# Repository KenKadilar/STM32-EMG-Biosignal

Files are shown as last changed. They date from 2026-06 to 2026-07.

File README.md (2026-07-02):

# CAN-Networked Real-Time Myoelectric Gripper Firmware

A self-contained myoelectric gripper on STM32 firmware: it reads a forearm muscle, classifies the gesture on-chip in real time, drives a gripper, reports its state over a CAN bus, and fails safe. It rebuilds the embedded layer of my M.Sc. prosthetic-hand thesis on industrial-grade firmware (STM32, FreeRTOS, CAN).

https://github.com/user-attachments/assets/c445c9bf-50ab-4b18-980c-f69603f6f55b

**~30s demo:** flex, the gripper actuates, the state broadcasts over CAN, then the failsafe (pull an electrode, the gripper holds).

**Tech stack:** STM32F446 (Cortex-M4F), FreeRTOS, CAN (MCP2515, hand-written register-level driver), on-chip DSP and classification, timer and DMA sensing, IWDG watchdog, PlatformIO, GitHub Actions CI

## What this is

The board is autonomous: the muscle drives everything, and the laptop is only a viewer. TIM2 triggers the ADC on the EMG pin at 1 kHz, DMA parks each sample in RAM, and a lightweight detector runs per sample inside the DMA-complete interrupt, so a flex is caught the instant it happens and handed to the FreeRTOS tasks through queues. The tasks drive the gripper, stream telemetry, broadcast state on the CAN bus, and pet the watchdog.

The hard biosignal part (single-channel sEMG gesture detection on a microcontroller) comes from my published thesis. The work here is the industrial-firmware layer around it: a real-time OS, a CAN stack written from the datasheet, on-chip DSP, and a safety layer.

## Highlights

- **One muscle, decided on-chip.** TIM2 to ADC to DMA at 1 kHz with zero CPU per sample; the baseline-tracking dip detector runs in the DMA ISR, so a flex is caught immediately.
- **FreeRTOS with a safety-by-priority design.** Four tasks (servo, comms, CAN, watchdog) with priorities and queue mailboxes. The watchdog task is the lowest priority on purpose: if any higher task hangs, it never runs, never pets the IWDG, and the chip reboots itself.
- **A CAN stack written from the datasheet.** There is no mature MCP2515 driver for STM32 and stm32cube, so the SPI instruction set, register map, and logic are hand-written, brought up in four verified steps, and checked end to end by a second CAN node.
- **On-chip DSP.** A 50 Hz biquad notch rejects mains hum before detection.
- **Fails safe.** A signal-loss hold keeps the current grip if an electrode drops, backed by a hardware IWDG watchdog.
- **A full-stack build.** The gripper is a 3D-printed involute-gear pincer I designed in SolidWorks and drove from a single SG90.

## Architecture

The board is autonomous; the laptop only flashes it and views the trace.

```mermaid
flowchart TD
    EMG[EMG sensor] --> ADC[ADC + DMA<br/>1 kHz]
    ADC --> BRAIN[Brain<br/>DMA ISR]
    BRAIN -->|flex| MB([mailBox])
    BRAIN -->|flex| CM([canMailBox])
    MB --> SV[servoTask] --> GR[Gripper]
    CM --> CT[canTask] --> BUS[CAN bus]
    ADC --> CO[commsTask] --> LAP[Laptop]
    WD[watchdogTask] --> IWDG[IWDG reboot]
```

The decision lives in the **interrupt**: `HAL_ADC_ConvCpltCallback` fires at 1 kHz on every DMA sample and runs the detector (baseline, notch, dip), then `xQueueSendFromISR`s a token into both `mailBox` (to servoTask) and `canMailBox` (to canTask). The token's existence is the signal that a flex happened; its value is unused, and the queues do their own locking, so there is no manual volatile or atomic reasoning.

Four tasks run under the scheduler (higher number is more urgent):

1. **servoTask (priority 3):** a token toggles the grip; `servo.ease()` glides toward the target each cycle (slew-limited). The 5 ms receive-timeout also paces it at about 200 Hz.
2. **commsTask (priority 2):** every 20 ms, streams the `raw, centered, valid` trace to the laptop viewer over USART2.
3. **canTask (priority 2):** a token sends an immediate gesture frame (0x100); a 200 ms timeout sends a status heartbeat (0x101). Both carry `[gripper closed?, electrode attached?]`.
4. **watchdogTask (priority 1, lowest):** every 500 ms, pets the IWDG. The low priority is the safety: a hung higher task starves it and the chip reboots.

## The CAN work

There is no mature MCP2515 driver for STM32 and stm32cube, so the driver is written from the datasheet by hand: the SPI instruction set and register map live in [`src/Mcp2515Registers.h`](src/Mcp2515Registers.h) (each constant carries its datasheet name) and the logic in [`src/Mcp2515CanBus.h`](src/Mcp2515CanBus.h). It was brought up in four verified steps:

1. **Reach the chip over SPI**, reset it, and read `CANSTAT` back (`0x80` = Configuration mode).
2. **Configure and go live**: set the bit timing (8 MHz crystal at 500 kbps) and switch to Normal mode.
3. **Loopback frame**: build a frame, transmit it internally, and read it back (no bus needed).
4. **Two-node transmit**: send real frames over `CANH/CANL` to a separate node.

In the running firmware the gripper broadcasts a 2-byte payload `[gripper closed?, electrode attached?]` as an immediate gesture frame (`0x100`) on each flex and a status heartbeat (`0x101`) otherwise. It is verified end to end by an independent second node, an Arduino plus MCP2515 that receives and prints the frames ([`bench/arduino_can_node/`](bench/arduino_can_node/)). That node uses an off-the-shelf library, so the two sides are a deliberate contrast: hand-written driver against a stock one.

| Logic-analyzer capture | |
|---|---|
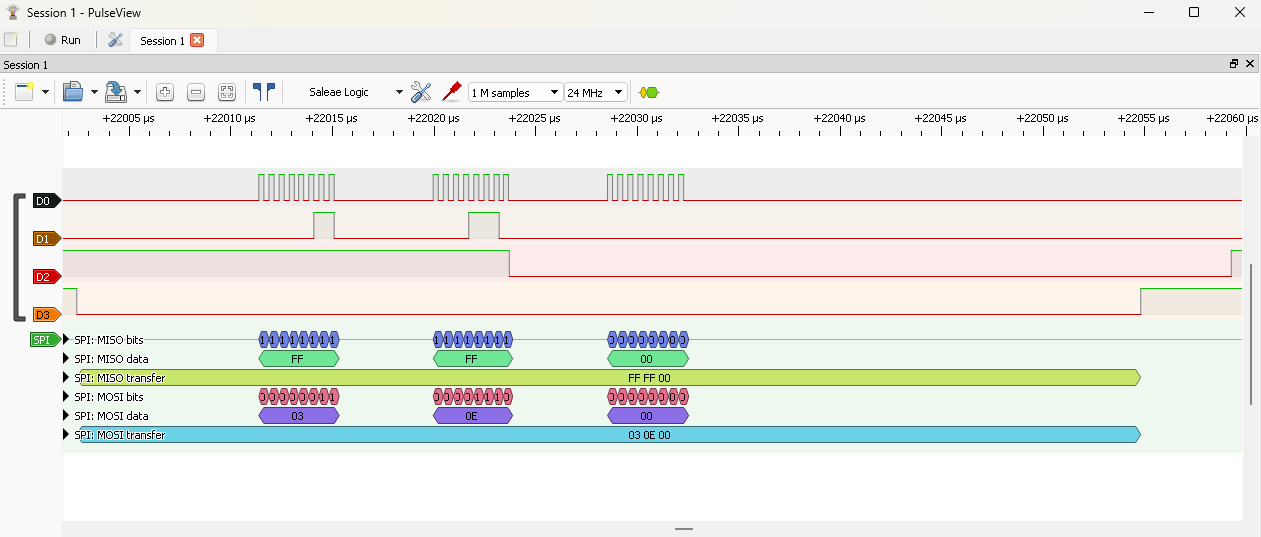
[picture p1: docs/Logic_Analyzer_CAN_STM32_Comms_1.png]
SPI decode
|  | The STM32 driving the MCP2515 over SPI, decoded live in PulseView. |

**Bus note:** the bench CAN bus is short and was initially unterminated (measured ~25 kΩ across CANH/CANL, transceiver impedance only), which produced occasional auto-retransmissions (CAN's reliability doing its job). Adding termination cleaned it up. A production harness uses 120 Ω at each end (60 Ω total).

## Mechanical

The gripper is a 3D-printed involute-gear pincer I designed in SolidWorks, so this is a full-stack mechatronics build: mechanism, electronics, and firmware.

<p>
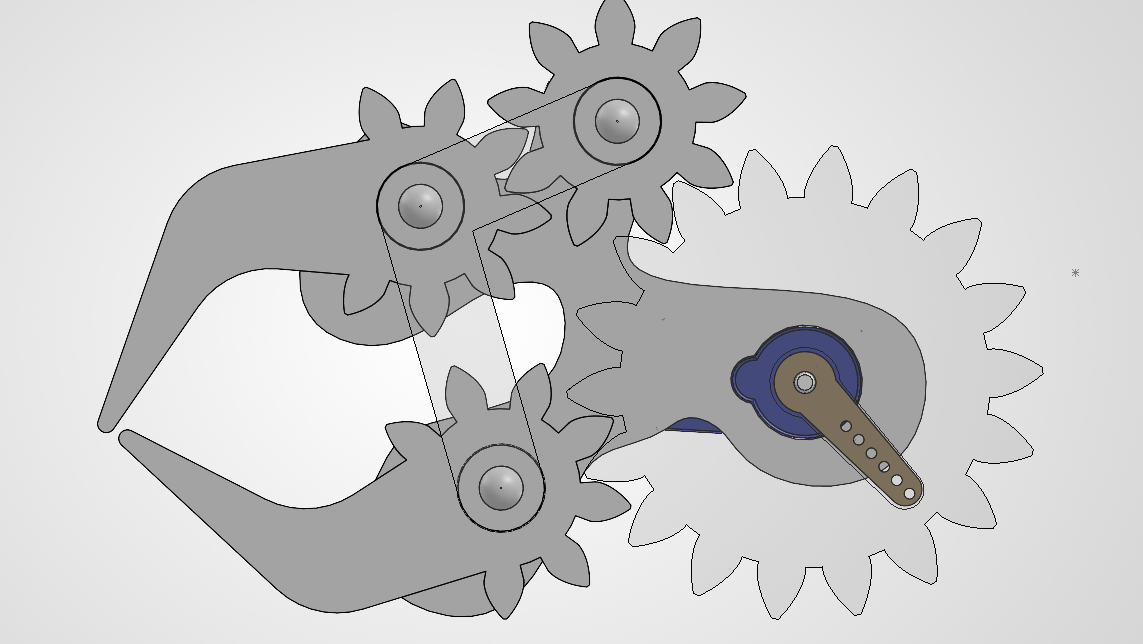
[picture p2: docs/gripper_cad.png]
Gripper CAD, top view
  
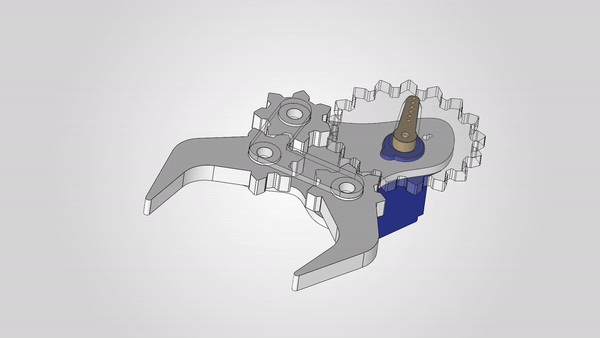
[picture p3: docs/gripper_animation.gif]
Gripper mechanism, open/close animation
  
</p>

A single SG90 drives a 28.5° pressure-angle involute spur train (z18 to z9 to z9), a 2:1 step-up to two counter-rotating fingers, giving about 108° of finger sweep in under 0.1 s and about 0.09 N·m per finger (the firmware slew-limits it so it does not slam). The gears were drawn with the in-repo `tools/gear_designer` (DXF export, undercut and bore checks).

### [Rotate the assembled gripper in 3D](cad/gripper_assembly.stl)

GitHub opens `.stl` files in an interactive 3D viewer; click the heading to spin the model. Printable parts are in [`cad/print_parts/`](cad/print_parts/).

## Specs

| Category | Value |
|---|---|
| MCU / board | STM32F446RE (Cortex-M4F, FPU + DSP), ST Nucleo-F446RE |
| RTOS | FreeRTOS, ARM_CM4F port, 4 tasks + 2 queue mailboxes |
| Sensing | TIM2-triggered ADC + DMA at 1 kHz on PA0 |
| On-chip DSP | 50 Hz biquad notch |
| Detection | baseline-tracking dip detector in the DMA ISR |
| CAN | MCP2515 over SPI2, hand-written driver, 8 MHz xtal at 500 kbps |
| Frames | gesture 0x100 + heartbeat 0x101, payload [closed?, electrode?] |
| Actuation | SG90 servo, slew-limited, on TIM4_CH1 (PB6) |
| Gear train | involute z18 to z9 to z9, 2:1 step-up, ~108° finger sweep |
| Safety | signal-loss hold + IWDG hardware watchdog (~2 s) |
| Tooling | PlatformIO (stm32cube, hard-float), GitHub Actions CI |

## Hardware and wiring

| Part | Pin | Notes |
|---|---|---|
| Grove EMG detector | PA0 (A0) | ADC1 analog envelope in |
| SG90 servo | PB6 (D10) | TIM4 channel 1, 50 Hz PWM |
| Serial TX | PA2 | USART2 over the ST-LINK virtual COM port (telemetry is one-way) |
| MCP2515 | SPI2: PB13 SCK, PB14 MISO, PB15 MOSI, PB12 CS, PA9 INT | 8 MHz xtal at 500 kbps |

SPI2 is chosen over SPI1 because SPI1's SCK is PA5, the onboard LED, which would flicker on every SPI clock. The servo runs on a separate 6 V (4xAAA) supply, not the Nucleo 5 V pin (its current spikes brown out the board); tie the servo supply ground to Nucleo GND so the PWM has a common reference. Board pinout: [`docs/STM32_NUCLEO_F446RE_Pinout.png`](docs/STM32_NUCLEO_F446RE_Pinout.png).

## Build, flash, run

PlatformIO (`framework = stm32cube`), flashed over the onboard ST-LINK.

```bash
pio run                 # build the firmware
pio run -t upload       # flash over ST-LINK (Mini-USB)

# watch the on-chip telemetry live (Python 3.12: numpy, pyserial, PyQt6, pyqtgraph)
python tools/emg_studio/chip_monitor.py --port COM6
```

The FreeRTOS ARM_CM4F port needs the FPU, so the whole image is hard-float. That takes two cooperating pieces, the `build_flags` in [`platformio.ini`](platformio.ini) and [`fpu_link.py`](fpu_link.py) (a post-script that forces the link hard-float). Both are required; removing either breaks the link. CI builds the firmware on every push.

## Bill of materials

Parts, sources, and prices (two CAN nodes, so it includes a second MCP2515 and an Arduino): [`BOM.md`](BOM.md).

## Repo structure

```
src/                 firmware: one main.cpp + a header-only class per part
  main.cpp           tasks, queues, scheduler, interrupt handlers, the 1 kHz brain callback
  Emg.h              TIM2 -> ADC -> DMA acquisition at 1 kHz
  MuscleTrigger.h    the on-chip brain (baseline, notch, dip detect, failsafe)
  Notch.h            50 Hz biquad notch
  Servo.h            slew-limited gripper PWM
  Comms.h            USB serial telemetry (TX)
  Watchdog.h         IWDG
  Mcp2515CanBus.h    hand-written MCP2515 CAN driver (logic)
  Mcp2515Registers.h the MCP2515 datasheet as code (commands, registers, values)
lib/FreeRTOS/        the kernel (ARM_CM4F port + heap_4), vendored, unedited
include/             FreeRTOSConfig.h
bench/arduino_can_node/  the second CAN node used to verify the link
tools/emg_studio/    laptop viewer/logger (chip_monitor.py)
tools/gear_designer/ the gear-profile tool used to draw the pincer
cad/                 the gripper assembly STL + printable parts
docs/                captures, CAD renders, board pinout
```

## Known limitations

- **One gesture** (a single muscle dip toggles open/close) by design; the multi-grip DTW classifier lives in the thesis, and this project's focus is the embedded system around it.
- **The CAN bus is a short bench setup** (two nodes, improvised termination), not a production 120 Ω-terminated harness.
- **The on-chip DSP is a hand-coded biquad notch**; for heavier filtering or FFT work, ARM's CMSIS-DSP (which the M4's DSP and FPU are built for) is the next step.
- **CAN is transmit-only** here (a sensor-actuator node reporting its state). Receive plus hardware ID filtering would be configured at the controller for a multi-node bus.

## Background and contact

This rebuilds the embedded layer of my M.Sc. thesis on single-channel sEMG gesture classification on a microcontroller:

- Journal article (IJANSER, 2024): https://as-proceeding.com/index.php/ijanser/article/view/1728
- Extended arXiv preprint: https://arxiv.org/abs/2504.15256

**Ken KADILAR** - embedded / firmware engineer  
Portfolio: [canarchive.com](https://canarchive.com)  
LinkedIn: [ken-kadilar](https://www.linkedin.com/in/ken-kadilar/)  
Email: kenkadilar@gmail.com

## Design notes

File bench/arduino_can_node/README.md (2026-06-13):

# Arduino CAN bench node

The **second CAN node** used to verify the STM32's CAN link end to end: first to prove the two MCP2515
modules + bus worked at all (before any STM32 CAN code existed), then as the receiver in the live
two-node demo. An Arduino UNO + an MCP2515 module (8 MHz crystal, 500 kbps), matching the STM32 side.

Note the deliberate contrast: this side uses the off-the-shelf **coryjfowler MCP_CAN** library, while the
STM32 side runs a **hand-written, register-level MCP2515 driver** ([`src/Mcp2515CanBus.h`](../../src/Mcp2515CanBus.h)
and [`src/Mcp2515Registers.h`](../../src/Mcp2515Registers.h)). The Arduino is only a known-good test partner.

- `src/receiver.cpp` (env `receiver`): prints every received frame; decodes the gripper's status (`0x101`)
  and gesture (`0x100`) frames into plain text (`servo=OPEN/CLOSED  electrode=ATTACHED/DETACHED`).
- `src/sender.cpp` (env `sender`): transmits test frames, used to validate the modules on the bench.

Build/flash one role per UNO (PlatformIO):

```
pio run -e receiver -t upload
pio run -e sender   -t upload
pio device monitor -e receiver
```

Wiring: MCP2515 over SPI (UNO D13 SCK / D11 SI / D12 SO / D10 CS / D2 INT, 5V + GND); CANH-CANH and
CANL-CANL to the other node, shared ground. See [`../../docs/wiring.md`](../../docs/wiring.md).

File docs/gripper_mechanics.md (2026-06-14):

# Gripper Mechanics, Gear Train Math

The drivetrain math for the 3D-printed involute-gear pincer. Gear values are Can's final printed
set (2026-06-08); SG90 specs from the datasheet.

## TWO THINGS TO CONFIRM (then the force/aperture numbers below compute)
1. **Which gear is on the servo shaft?** This doc assumes the **z18 is the input** (servo side),
   driving the two z9 fingers. If the servo actually drives a **z9** instead, the ratio inverts
   (see "If the servo is on a z9" below).
2. **Finger lever length `L`** = distance from a finger gear's centre to its contact/tip point
   (mm). Needed for pinch force and aperture. Measure it off the CAD/print.

## Gear set (printed)
| | teeth z | pitch d | tip (outer) d | root (inner) d |
|---|---|---|---|---|
| input gear | 18 | 48.60 | 54.00 | 41.85 |
| finger gear A | 9 | 24.30 | 29.70 | 17.55 |
| finger gear B | 9 | 24.30 | 29.70 | 17.55 |

Common: module **m = 2.70 mm**, pressure angle **28.5°**, bore 10.00 mm, backlash 0.10 mm.
Sanity (all consistent): pitch = m*z, tip = m(z+2), root = m(z-2.5), centre = m(z1+z2)/2.
At 28.5° the no-undercut minimum is ~9 teeth, so the z9 gears are right at the limit (the high
pressure angle is what lets them work at 9 teeth, a deliberate, correct choice).

## Train topology (assumed)
```
  SERVO --(z18)--mesh--(z9, finger A)--mesh--(z9, finger B)
```
- Centre distances: z18 to z9 = **36.45 mm**, z9 to z9 = **24.30 mm** (match the printed frame).
- Fingers A and B **counter-rotate** (z9 to z9, 1:1), a symmetric pincer. Good.

## Gear ratio (servo to finger)
Servo drives z18; fingers are z9. Driven/driver teeth = 18/9, so:
- **Fingers rotate 2× the servo angle** (a 2:1 *step-up*).
- **Finger torque = servo torque ÷ 2.**
- This trades torque for travel: the SG90's limited usable sweep becomes 2× as much finger
  rotation, sensible for a gripper that needs range and has torque to spare.

*If the servo is on a z9 instead:* it becomes a 2:1 *step-down*, fingers move 1/2 the servo angle,
finger torque = servo torque × 2 (more grip force, less range). Flip the numbers below accordingly.

## Servo sweep to finger sweep
- Pulse band (measured): open **1300 µs**, close **1600 µs**, giving **300 µs** of travel.
- SG90 ≈ 0.18°/µs (≈180° over 1000 µs; **calibrate yours**, SG90s vary): 300 µs ≈ **54° servo**.
- Finger sweep = 54° × 2 = **~108° per finger.**

## Speed
- SG90: 0.10 s / 60° = **600°/s** (no load). Finger = ×2 = **1200°/s**.
- 108° finger sweep ≈ **0.09 s** open to close at full speed. (The firmware slew-limits this on
  purpose, the mechanism is faster than you'd want it to slam.)

## Torque & pinch force
- SG90 stall ≈ **1.8 kgf·cm = 0.176 N·m** at 4.8 V (higher at 6 V, measure if it matters).
- Finger gear torque (÷2) = **0.088 N·m**.
- Fingertip pinch force: `F_tip = 0.088 N·m / (L/1000)` = **88 / L_mm  newtons**.
  - e.g. L = 30 mm gives ~2.9 N. L = 40 mm gives ~2.2 N. L = 50 mm gives ~1.8 N.
  - (That's *stall* / theoretical max; working force is lower. Plenty for light objects,
    consistent with a hobby-servo pincer.)

## Aperture (opening between fingertips)
Each finger sweeps up to ~108°. For symmetric counter-rotating fingers of lever `L`, the tip-to-tip
opening change ≈ `2 * L * sin(Δθ/2)` over the sweep `Δθ` actually used (≤108°). Plug in `L` and the
real open/close angle endpoints to get the mm aperture. (Needs the finger geometry / CAD.)

## One-line summary for the portfolio
"Single SG90 drives a 3D-printed 28.5°-pressure-angle involute spur train (z18 to z9 to z9), 2:1
step-up to two counter-rotating fingers, ~108° sweep in <0.1 s, ~0.09 N·m per finger."
(Designed with the in-repo `tools/gear_designer`, DXF export, undercut/bore checks.)

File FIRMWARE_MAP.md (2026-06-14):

# Firmware map

Navigation for `src/` + the FreeRTOS layout. The single place that says what each piece does, so the
files stay clean (no big header banners). One file = one part of the device.

Board: NUCLEO-F446RE. Chip: STM32F446RE. Language: C++ (header-only classes) + the FreeRTOS kernel in
`lib/`. Build: PlatformIO (`framework = stm32cube`), **hard-float** (see platformio.ini + fpu_link.py).
Flash: `pio run -t upload`.

## Files (in `src/`)

| File | What it is |
|---|---|
| `main.cpp` | Builds the parts + the two queues (`mailBox`, `canMailBox`), creates the 4 FreeRTOS tasks, calls `vTaskStartScheduler()`, and holds the interrupt handlers: SysTick (chained to HAL + kernel), the 1 kHz ADC/DMA brain callback, and the DMA stream IRQ. |
| `Emg.h` | `Emg` : the muscle sensor. TIM2 triggers the ADC on PA0 at 1 kHz and DMA parks each result in RAM; `read()` returns the freshest sample (no CPU per reading). |
| `MuscleTrigger.h` | `MuscleTrigger` : the on-chip brain. Tracks the resting baseline, centers the signal (through the notch), and returns `true` once per valid flex (a "dip"). Includes the signal-loss failsafe; `isElectrodeAttached()` for telemetry. |
| `Notch.h` | `Notch` : a 50 Hz biquad notch; `filter()` kills mains hum (used by MuscleTrigger). |
| `Servo.h` | `Servo` : the gripper. PWM on PB6 (TIM4 ch 1). `open()`/`close()`/`toggle()` choose a position; `ease()` glides toward it (slew-limited); `isClosed()` for telemetry. |
| `Comms.h` | `Comms` : one-way USB serial telemetry (USART2 TX). `sendStatus(raw, centered, valid)` streams the trace to the laptop viewer. |
| `Watchdog.h` | `Watchdog` : hardware IWDG (~2 s). `pet()` resets it; if nothing pets it, the chip reboots. |
| `Mcp2515CanBus.h` | `Mcp2515CanBus` : hand-written MCP2515 CAN driver (the logic). SPI2 bring-up, reset, register read/write, bit timing, mode select, `sendFrame()` / `readFrame()`. |
| `Mcp2515Registers.h` | The MCP2515 datasheet as code: every command byte, register address, and bit-field value, each with its datasheet name in the comment. |

## FreeRTOS layout

- `lib/FreeRTOS/`, the kernel (`tasks.c`/`list.c`/`queue.c`), the `ARM_CM4F` port (`port.c` +
  `portmacro.h`), `heap_4.c`, and the headers. Vendor code, copied from the stm32cube package, not edited.
- `include/FreeRTOSConfig.h`, OUR config (16 MHz HSI clock, 1 kHz tick, 10 KB heap, PendSV/SVC mapped
  to the port). In `include/` so both our code and the kernel see it; the vendor folder stays pure.
- Hard-float is mandatory for the CM4F port. The wiring is `platformio.ini` `build_flags` +
  `fpu_link.py` (the link half). Do NOT remove either, the build breaks (see the build note in the README).

## The 1 kHz brain + the four tasks

The brain runs in an **interrupt**, not a task. `HAL_ADC_ConvCpltCallback` fires at 1 kHz (every DMA
sample) and runs `trigger.update(emg.read())`: baseline + centering + notch + dip detection. On a valid
flex it `xQueueSendFromISR`s a token into BOTH `mailBox` (-> servoTask) and `canMailBox` (-> canTask),
then `portYIELD_FROM_ISR`s.

Four tasks (priorities: higher number = more urgent; idle is 0):
1. `servoTask` (**pri 3**, highest): `xQueueReceive(mailBox, ..., 5 ms)`. Token -> `servo.toggle()`;
   `servo.ease()` every cycle. The 5 ms receive-timeout doubles as the ~200 Hz pacing.
2. `commsTask` (**pri 2**): every 20 ms (~50 Hz) -> `comms.sendStatus(raw, centered, valid)`.
3. `canTask` (**pri 2**): `xQueueReceive(canMailBox, ..., 200 ms)`. A token -> immediate **gesture frame
   (0x100)**; a timeout -> **status heartbeat (0x101)**. Both carry `[gripper closed?, electrode attached?]`.
4. `watchdogTask` (**pri 1**, lowest on purpose): every 500 ms -> `watchdog.pet()`. Lowest priority IS
   the safety: a hung higher task starves it -> no pet -> IWDG reboots.

Interrupt handlers (bottom of `main.cpp`): `SysTick_Handler` -> `HAL_IncTick()` + (once scheduler up)
`xPortSysTickHandler()`; `HAL_ADC_ConvCpltCallback` = the brain; `DMA2_Stream0_IRQHandler` ->
`emg.handleDmaIrq()`. PendSV/SVC handlers are the port's, named via FreeRTOSConfig `#define`s.

## The two queues (brain -> tasks)

`mailBox` and `canMailBox`, each `xQueueCreate(4, sizeof(uint8_t))`. The brain drops one token per flex
into **both**: servoTask acts (toggle), canTask announces (CAN gesture frame). The queues do their own
locking, so no manual `volatile`/atomic reasoning. The token's *value* is unused; its *existence* is the
"a flex happened" signal. `canMailBox` is created before `mailBox`, so the `mailBox != NULL` ISR guard
(queues are NULL until the scheduler is set up) covers both.

## CAN driver (`Mcp2515CanBus.h` + `Mcp2515Registers.h`)

Hand-written from the datasheet (no mature STM32 MCP2515 library). SPI2 (PB13/14/15 + PB12 CS), 8 MHz
crystal @ 500 kbps, Normal mode. The board broadcasts a gesture frame (0x100) and a status heartbeat
(0x101); a second node (`bench/arduino_can_node/`) receives and decodes them. See README "The CAN work"
and `docs/wiring.md`.

## Where the "thinking" is

On the chip (`MuscleTrigger`): baseline track + center + notch + dip -> toggle, with a failsafe that
holds if the signal goes bad. The laptop is just a viewer of the `raw,centered,valid` stream
(`tools/emg_studio/chip_monitor.py`). The board runs standalone.

## On-chip detector knobs (`MuscleTrigger.h`)

| Knob | Value | Meaning |
|---|---|---|
| `DIP_THRESHOLD` | 425 | centered must dip this far below rest to count as a flex |
| `REARM_LEVEL` | 150 | ...and climb back above -this to re-arm for the next flex |
| `LOCKOUT` | 125 | samples (~125 ms at 1 kHz) after a release before another flex counts (bounce guard) |
| `RAIL_HIGH` / `RAIL_LOW` | 3000 / 25 | raw outside this band = bad signal (failsafe) |
| `VALID_AFTER` | 1000 | clean samples in a row (~1 s) needed to trust the signal again |

## Pins

| Part | Pin | Notes |
|---|---|---|
| EMG sensor | PA0 (A0) | ADC1 analog input |
| Servo | PB6 (D10) | TIM4 channel 1, PWM at 50 Hz |
| Serial TX | PA2 | USART2 TX over the ST-LINK virtual COM port (RX unused, telemetry is one-way) |
| CAN (MCP2515) | SPI2: PB13 SCK / PB14 MISO / PB15 MOSI + PB12 CS + PA9 INT | 8 MHz xtal @ 500 kbps, see docs/wiring.md |

(Mechanical/CAD assets live in `cad/` + `docs/`; see the README "Mechanical" section.)

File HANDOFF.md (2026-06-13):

# STM32-EMG-Biosignal , HANDOFF (as of 2026-06-14)

Read this when continuing in a fresh chat. Repo: CanGitArchive/STM32-EMG-Biosignal at
`S:\Coding\STM32-EMG-Biosignal`. Owner: Can KADILAR. Second hardware portfolio piece (after the EMG
prosthetic-hand thesis): a myoelectric gripper on real STM32 firmware. **Going PUBLIC for the portfolio.**

> READ FIRST , how to work with Can: `S:\Coding\CodingPlaybooks\CODING_STYLE_PLAYBOOK.md`
> (ONE STEP AT A TIME: propose -> explain plainly -> get his go -> implement -> verify on hardware;
> NO autonomous multi-agent / ultracode). GOAL + history:
> `S:\Coding\ChatAssistants\HealthAssistant\CareerAssistant\STM32_project_goals.md` (latest = Handoff 8)
> + `STM32_Project_Scope.md`. File-by-file nav: `FIRMWARE_MAP.md`.

## AUDIT FIRST (a rule earned the hard way)

Trust nothing in this file until you check it against `git log` + the actual `src/` files. Past handoffs
corrupted the plan by trusting prose over code. Verify any "done" claim against the code.

## STATE: COMPLETE , standalone gripper, on-chip + FreeRTOS + CAN + safety, VERIFIED (2026-06-14)

Every target competency is demonstrated on real hardware, in one running device:
- **Acquisition is hardware** (`Emg.h`): TIM2 -> ADC -> DMA at 1 kHz, no CPU per sample.
- **The 1 kHz brain** (`MuscleTrigger.h` + `Notch.h`) runs in `HAL_ADC_ConvCpltCallback`: baseline +
  50 Hz notch + centering + dip detection + signal-loss failsafe. On a flex it drops a token into BOTH
  `mailBox` and `canMailBox`.
- **Four FreeRTOS tasks** (`main.cpp`): `servoTask` (pri 3, toggle), `commsTask` (pri 2, serial
  telemetry), `canTask` (pri 2, CAN gesture 0x100 + status heartbeat 0x101), `watchdogTask` (pri 1,
  lowest = watchdog-starvation reboot).
- **CAN** is a hand-written MCP2515-over-SPI driver (`Mcp2515CanBus.h` + `Mcp2515Registers.h`), verified
  two-node against the Arduino node in `bench/arduino_can_node/`.

VERIFIED on hardware: a flex toggles the gripper and fires a `GESTURE` frame; idle sends `Status`
heartbeats; pulling an electrode -> gripper holds + `electrode=DETACHED` on CAN; no reboot loop.

## CRITICAL build note: hard-float wiring is load-bearing, do NOT "simplify" it

The ARM_CM4F FreeRTOS port emits FPU context-switch instructions, so the ENTIRE image must be hard-float.
On this ststm32 platform that takes BOTH halves: `platformio.ini` `build_flags`
(`-mfpu=fpv4-sp-d16 -mfloat-abi=hard`) compile everything hard, AND `fpu_link.py` (a `post:` script)
forces the LINK hard (build_flags do NOT reach the ststm32 link step). Delete or "tidy" either one and
the link dies with "uses VFP register arguments, firmware.elf does not". This cost 4 failed attempts to map.

## FreeRTOS layout

- `lib/FreeRTOS/`: the kernel + `ARM_CM4F` port + `heap_4.c` + headers, copied from the stm32cube package
  (vendor, not edited).
- `include/FreeRTOSConfig.h`: OUR config (16 MHz HSI, 1 kHz tick, 10 KB heap,
  `configMAX_SYSCALL_INTERRUPT_PRIORITY` = 5, PendSV/SVC mapped to the port). In `include/` so the vendor
  folder stays pure.

## Hardware / wiring

- Nucleo-F446RE (Cortex-M4F), Mini-USB (not micro), HSI 16 MHz (no SystemClock_Config, deliberate).
  pio CLI: `~/.platformio/penv/Scripts/pio.exe` (NOT on PATH; call it with the PowerShell `&` operator).
- EMG: Grove EMG Detector analog out -> PA0 / A0 (ADC1).
- Servo: SG90 on TIM4_CH1 / PB6. V+ -> separate 6 V pack, GND -> battery AND Nucleo GND (shared ground
  mandatory). Measured: open 1300 us, close 1600 us.
- CAN: MCP2515 on SPI2 (PB13 SCK / PB14 MISO / PB15 MOSI / PB12 CS / PA9 INT), 8 MHz crystal @ 500 kbps.
  **Bus needs ~120 ohm termination across CANH-CANL**; unterminated -> occasional auto-retransmit
  duplicates (CAN reliability working). See `docs/wiring.md`.

## CAN: DONE, integrated, verified two-node

- Hand-written driver (no mature STM32 MCP2515 lib). Brought up in 4 verified steps: SPI reach the chip
  (CANSTAT = 0x80) -> bit timing + Normal mode -> loopback frame -> two-node transmit.
- Second node: `bench/arduino_can_node/` (Arduino UNO + MCP2515, coryjfowler MCP_CAN). `receiver.cpp`
  decodes the 0x100 (gesture) / 0x101 (status) frames to plain text.
- Captures: `docs/Logic_Analyzer_CAN_STM32_Comms_1..4.png` (STM32 SPI decode),
  `docs/Logic_Analyzer_CAN_Comms.png` (Arduino bench).

## Mechanical / CAD (portfolio assets)

Gripper designed in SolidWorks. `docs/gripper_cad.png` (render), `docs/gripper_animation.gif` (open/close
motion), `cad/gripper_assembly.stl` (GitHub 3D viewer) + `cad/print_parts/*.stl`. Gear math in
`docs/gripper_mechanics.md`; the gear-design tool in `tools/gear_designer/`. CAD source folders are
recorded in `...\CareerAssistant\career_information_navigation.md`.

## Laptop tools (`tools/emg_studio/`)

- `chip_monitor.py` , the viewer for the on-chip stream. Run with **Python 3.12**:
  `python tools\emg_studio\chip_monitor.py --port COM6`. (`operate.py`/`emg_studio.py`/`calibrate.py`
  predate the on-chip port.)

## Build / flash / CI

- Build: `& "C:\Users\kadil\.platformio\penv\Scripts\pio.exe" run -d "S:\Coding\STM32-EMG-Biosignal"`.
  Flash: add `-t upload` (ST-LINK over Mini-USB). CI builds `pio run` on every push.
- Commit: `git commit -m "subject" -m "body"` (NOT a piped here-string , it once injected a BOM into a
  commit title). Commit only when Can asks.

## DONE vs OPEN

**DONE + on hardware:** STM32/HAL, RTOS (4 tasks + 2 queues + watchdog-starvation safety), on-chip dip
classifier, servo control, DSP (50 Hz notch), timer+DMA sensing, signal-loss failsafe + IWDG, **CAN
(hand-written driver, two-node, integrated as gesture + heartbeat)**, Git/CI, README, demo video, CAD/STL,
BOM.

**OPEN (shipping tail only):**
- Flip the repo **PUBLIC** (it's clean: no secrets, good history).
- In the GitHub web editor, **drag `docs/demo_video_STM32.mp4` into the README hero spot** (marked with
  an HTML comment) for an inline player. `docs/gripper_animation.gif` already embeds.
- Feature on `canarchive.com`; add `STM32 / FreeRTOS / CAN` to the CV's embedded line.
- Optional: a GIF hero of the demo; CMSIS-DSP library swap; RX + hardware ID filter (deliberately skipped,
  off-narrative for a TX-only sensor/actuator node, the choice is documented in the README limitations).

## Reference docs in this repo

`FIRMWARE_MAP.md` (src nav) · `docs/wiring.md` · `docs/BOM.md` · `docs/gripper_mechanics.md` ·
`docs/lessons_learned.md` · `docs/emg_noise_findings.md` · `bench/arduino_can_node/README.md`.

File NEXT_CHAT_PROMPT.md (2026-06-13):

# Paste this whole file into the next chat (STM32 EMG project, chat 9)

You are continuing Can KADILAR's STM32 EMG-gripper project. **The engineering is DONE and verified on
hardware.** What remains is the shipping tail (make public, portfolio, CV). STOP and read the files below
before writing or running anything. Use the EXACT ABSOLUTE PATHS below; never search by filename
(there are ~200 unrelated "handoff" files across this coding space).

## RULE #1 , HOW TO WORK WITH CAN (read this first)

Go ONE STEP AT A TIME: propose -> explain in plain language -> discuss -> get his "go" -> implement ->
verify on the real hardware -> next step. Do NOT run ahead, do NOT build several things before he weighs
in, and do NOT use autonomous multi-agent / "ultracode" on his code (a 5th-session ultracode run
autonomously built a FreeRTOS port and had to be rolled back entirely).

Can is a 15-year self-taught polyglot (C, C++, C#, Java, Python, PIC, Unreal/Unity/Godot). He is NOT a
beginner at programming logic , don't condescend. He IS often new to STM32 / embedded jargon , decode
acronyms plainly the first time. He learns by discussion and edits the code himself; slower-but-understood
beats fast-but-opaque. He will ask the SAME thing several ways until it clicks , answer each angle fresh.
He catches AI-tells (em-dashes, the `·` interpunct, "Not-A syndrome" negations that plant bad words like
"not Arduino") , keep public/Can-facing text clean: **no em-dashes or en-dashes**, no interpunct, no
hobbyist-planting negations. Read `S:\Coding\CodingPlaybooks\CODING_STYLE_PLAYBOOK.md` FIRST.

## RULE #2 , AUDIT BEFORE YOU TRUST

Earlier chats corrupted the plan by trusting the previous handoff instead of the code. Trust NO
"done/settled" claim (including in THIS file) until you verify it against `git log` + the actual files.
The FIRST chat is the source of truth: `STM32_project_goals.md` "Initial handoff" (the 0-9 steps). If you
find a contradiction, FLAG it to Can.

## The locations (read in this order)

1. GOAL + history , `S:\Coding\ChatAssistants\HealthAssistant\CareerAssistant\STM32_project_goals.md`
   (read the latest section, "## Handoff 8", last).
2. SCOPE , `S:\Coding\ChatAssistants\HealthAssistant\CareerAssistant\STM32_Project_Scope.md`.
3. STYLE , `S:\Coding\CodingPlaybooks\CODING_STYLE_PLAYBOOK.md`.
4. BUILD STATE , `S:\Coding\STM32-EMG-Biosignal\HANDOFF.md`.
5. NAV , `S:\Coding\STM32-EMG-Biosignal\FIRMWARE_MAP.md`.
6. CAREER INDEX , `S:\Coding\ChatAssistants\HealthAssistant\CareerAssistant\career_information_navigation.md`
   (CV, LinkedIn, publications, portfolio, CAD source folders, job log).

## The repo

`S:\Coding\STM32-EMG-Biosignal` (CanGitArchive/STM32-EMG-Biosignal, `gh` authed). Firmware = `src/`
(C++ header-only classes) + `lib/FreeRTOS/`. CAN driver = `Mcp2515CanBus.h` + `Mcp2515Registers.h`.
Bench second node = `bench/arduino_can_node/`. CAD = `cad/` + `docs/`. (VERIFY commits with `git log`.)

## State in one paragraph (VERIFY against the code)

COMPLETE. Standalone myoelectric gripper on real STM32 firmware: TIM2 -> ADC -> DMA at 1 kHz; the 1 kHz
brain (baseline + 50 Hz notch + dip detection + failsafe) runs in `HAL_ADC_ConvCpltCallback` and drops a
token into BOTH `mailBox` and `canMailBox`. Four FreeRTOS tasks: servoTask (pri 3), commsTask (pri 2),
canTask (pri 2, CAN gesture 0x100 + status heartbeat 0x101), watchdogTask (pri 1 lowest = starvation
reboot). CAN is a hand-written MCP2515-over-SPI driver, verified two-node against the Arduino node. All
verified on hardware. Hard-float wiring (platformio.ini + fpu_link.py) is load-bearing, do not "simplify".

## DONE vs OPEN

DONE: every competency (STM32, RTOS, CAN, on-chip DSP + classification, control, safety, Git/CI) + README
+ demo video + CAD/STL + BOM. OPEN (shipping tail only): flip the repo PUBLIC; on GitHub, drag
`docs/demo_video_STM32.mp4` into the README hero (HTML-comment marker) for an inline player; feature on
`canarchive.com`; add `STM32 / FreeRTOS / CAN` to the CV embedded line. Optional: GIF hero; CMSIS-DSP swap;
RX + hardware ID filter (deliberately skipped, off-narrative, documented in README limitations).

## SETTLED decisions , do NOT re-open

- ONE gesture only: a single dip toggles open/close (the thesis owns multi-grip DTW).
- C++ header-only classes; no big AI banner comments.
- CAN is TX-only in the product (gesture + heartbeat); RX/filter deliberately skipped.
- Hard-float build wiring required; do not remove platformio.ini flags or fpu_link.py.

## Build / flash / verify

- Build: `& "C:\Users\kadil\.platformio\penv\Scripts\pio.exe" run -d "S:\Coding\STM32-EMG-Biosignal"`
  (pio NOT on PATH; use the PowerShell `&`). Flash: add `-t upload` (ST-LINK over Mini-USB).
- Viewer: `python tools\emg_studio\chip_monitor.py --port COM6` , Python 3.12. CAN second node:
  `bench/arduino_can_node/` (`pio run -e receiver -t upload`, monitor COM8).
- Commit: `git commit -m "subject" -m "body"` (NOT a piped here-string). Commit only when Can asks.

## HARD RULES

- No em-dashes / en-dashes / `·` interpunct, and no hobbyist-planting negations, in any public/Can-facing text.
- One step at a time; no autonomous multi-agent / ultracode.
- When you hand off: append "## Handoff 9 (date)" to `STM32_project_goals.md` (do not edit earlier
  sections), refresh THIS file + `HANDOFF.md` + `FIRMWARE_MAP.md`, keep the AUDIT section so chat 10 starts skeptical.

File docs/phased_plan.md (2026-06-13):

# Phased plan (build checklist) , COMPLETE

All phases done and verified on hardware (2026-06-14). Kept as a record of the build order.

Legend: `[x]` done · `[ ]` deliberately not done (noted).

## 0. Toolchain
- [x] PlatformIO + `stm32cube`, ST-LINK flash/debug over Mini-USB
- [x] Blink LD2 (toolchain proof); GitHub Actions CI (`pio run`) green on every push

## Sensing , EMG acquisition
- [x] TIM2-triggered ADC + DMA at 1 kHz (`Emg.h`), no CPU per sample
- [x] Read Grove EMG on PA0; characterized noise (`docs/emg_noise_findings.md`)

## DSP
- [x] 50 Hz mains-rejection notch biquad (`Notch.h`) on the centered signal at 1 kHz
- [ ] CMSIS-DSP library swap , optional, the notch already demonstrates on-chip DSP

## Classification (on-chip)
- [x] Baseline tracking + centering + dip detector (`MuscleTrigger.h`): one flex = one toggle
- [x] Signal-loss failsafe (railing/unplugged -> hold, re-trust after ~1 s)
- DTW multi-grip stays in the thesis by design; this project's classifier is the lightweight dip detector

## Actuation
- [x] PWM the SG90 servo (TIM4_CH1 / PB6), slew-limited ease; separate 6 V supply, shared ground
- [x] Driven by the on-chip gesture (integrated)

## FreeRTOS
- [x] Kernel integrated (ARM_CM4F port, hard-float wiring: `platformio.ini` + `fpu_link.py`)
- [x] 4 tasks (servo / comms / can / watchdog) + 2 queues (`mailBox`, `canMailBox`); brain in the DMA ISR
- [x] Watchdog as the lowest-priority task = watchdog-starvation reboot

## CAN
- [x] Hand-written MCP2515-over-SPI driver (`Mcp2515CanBus.h` + `Mcp2515Registers.h`)
- [x] Two-node transmit verified against the Arduino node (`bench/arduino_can_node/`)
- [x] Integrated: gesture frame (0x100) + status heartbeat (0x101)
- [ ] RX + hardware ID filter , deliberately skipped (off-narrative for a TX-only node; see README limitations)

## Safety
- [x] Signal-loss failsafe (`MuscleTrigger.h`)
- [x] IWDG watchdog (~2 s), verified by a deliberate hang test

## Ship
- [x] README (scope + architecture + the CAN story + mechanical + BOM + contact)
- [x] Demo video (`docs/demo_video_STM32.mp4`)
- [x] CAD render + animation GIF + printable STLs (`cad/`, `docs/`)
- [x] CI green on every push
- [ ] Flip repo public + feature on canarchive.com + add STM32 / FreeRTOS / CAN to the CV embedded line

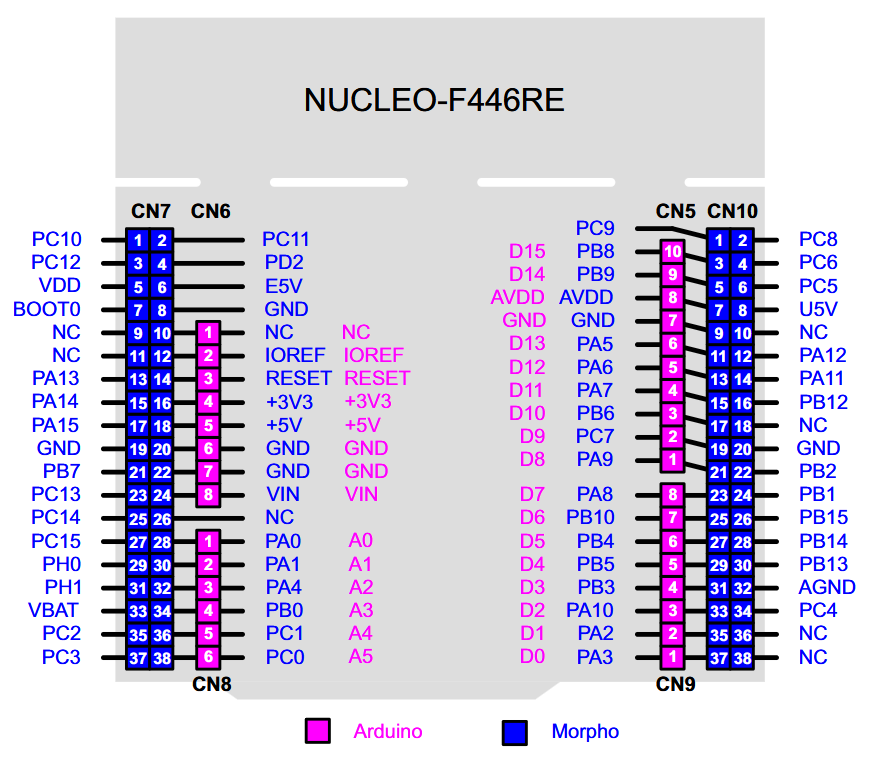
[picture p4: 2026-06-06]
docs/STM32_NUCLEO_F446RE_Pinout.png

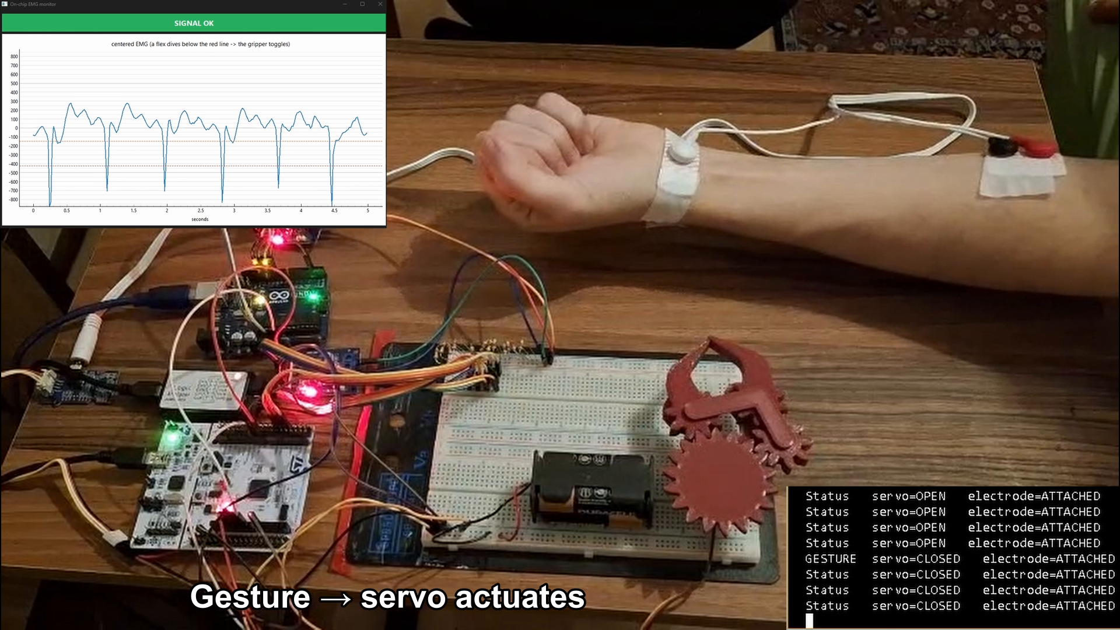
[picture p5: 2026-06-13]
docs/demo_still.png

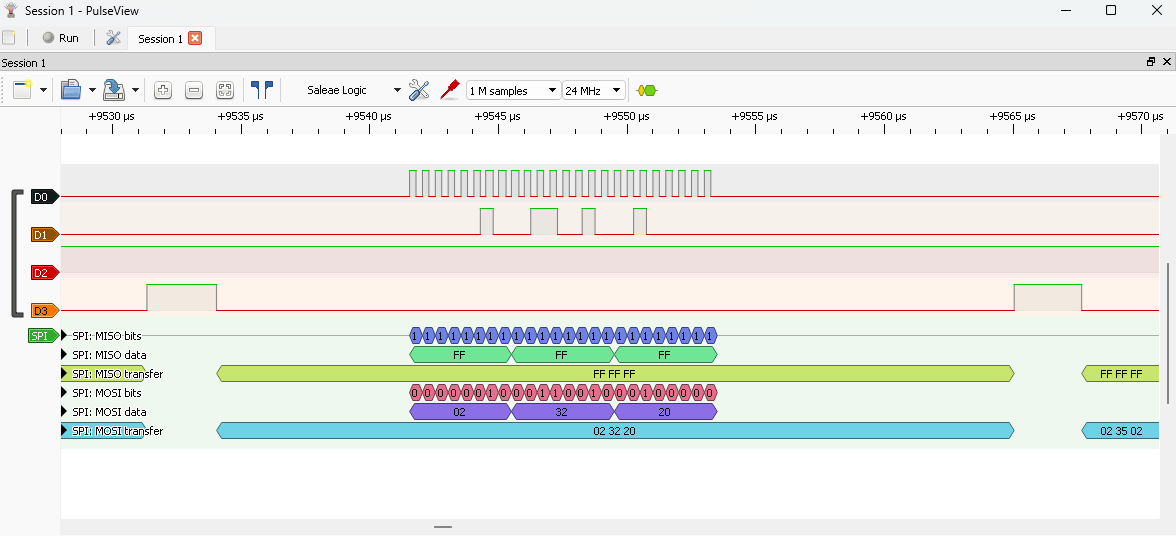
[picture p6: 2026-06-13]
docs/Logic_Analyzer_CAN_STM32_Comms_4.png

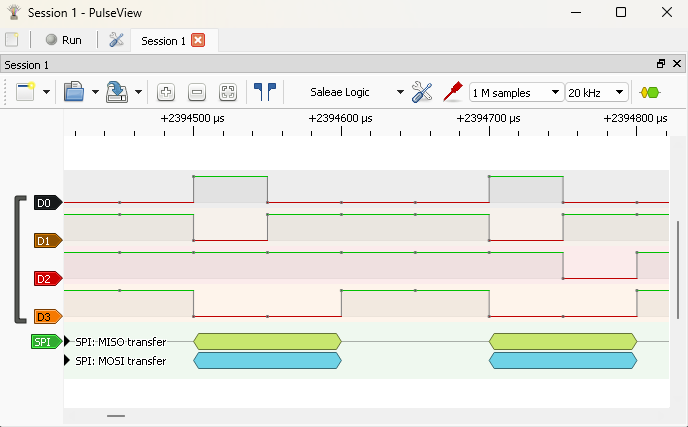
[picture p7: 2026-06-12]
docs/Logic_Analyzer_CAN_Comms.png

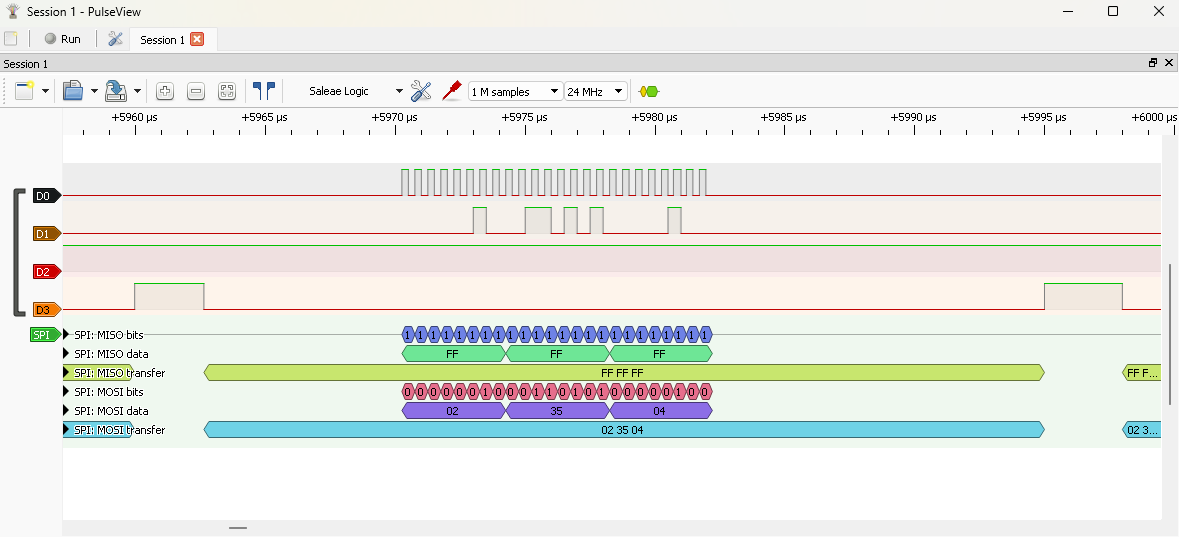
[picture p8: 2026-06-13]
docs/Logic_Analyzer_CAN_STM32_Comms_3.png

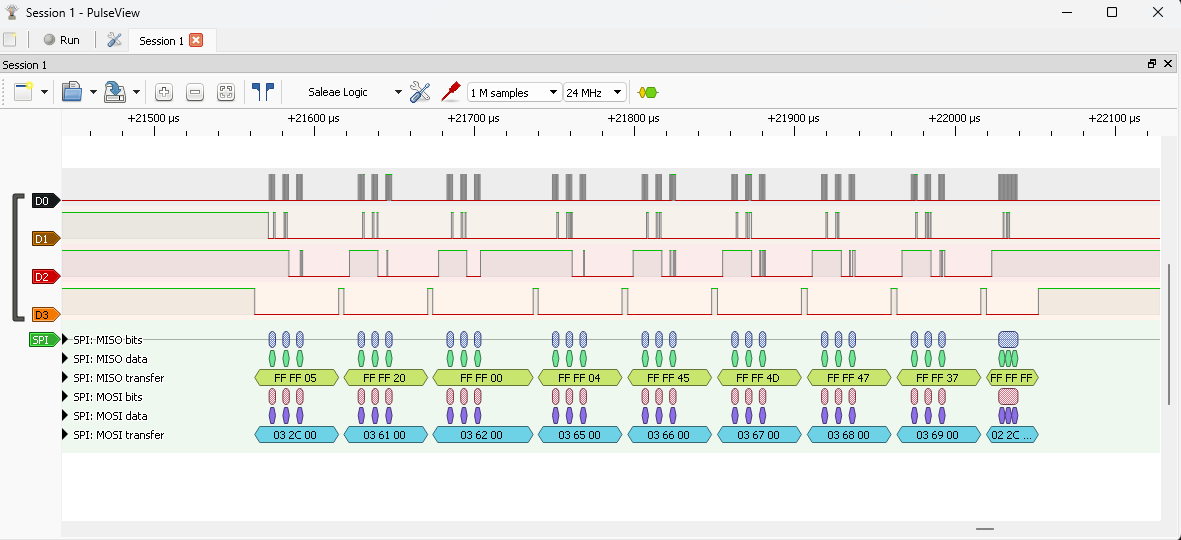
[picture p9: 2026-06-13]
docs/Logic_Analyzer_CAN_STM32_Comms_2.png

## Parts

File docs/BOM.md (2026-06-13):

# Bill of materials

Parts to reproduce this build. Most were bought from **Robotistan** (Istanbul) on **2026-06-04**;
prices are in Turkish Lira as paid, treat as indicative (they drift, and the build is two CAN nodes,
so it includes a second MCP2515 and an Arduino).

| Part | Qty | Role | Price (TL, as paid) |
|---|---:|---|---:|
| ST Nucleo-F446RE | 1 | the MCU board (Cortex-M4F, onboard ST-LINK) | 1380.12 |
| MCP2515 CAN module (controller + transceiver, SPI) | 2 | one per CAN node (STM32 side + Arduino bench node) | 205.97 |
| TowerPro SG90 servo, 180° | 2 | gripper actuation (clones arrive weak, the 2nd is a spare) | 156.72 |
| USB logic analyzer, 24 MHz 8-channel | 1 | SPI/CAN protocol decode (oscilloscope substitute for digital) | 364.92 |
| Mini-USB cable, 150 cm | 1 | powers + flashes the Nucleo (Mini-USB, not micro/USB-C) | 43.66 |
| Jumper wires F-F, 200 mm (40-pin) | 1 | breadboard wiring | 45.34 |
| Jumper wires M-M, 200 mm (40-pin) | 1 | breadboard wiring | 55.41 |
| Jumper wires M-F, 200 mm (40-pin) | 1 | breadboard wiring | 52.61 |
| Grove EMG Detector (Seeed) | 1 | analog EMG envelope into the ADC (already owned) | ~$30 USD |

**Already on hand (not re-bought):** a breadboard, EMG electrodes, a 6 V battery pack (4×AAA) for the
servo, an **Arduino UNO** for the second CAN node, a multimeter, and ~120 Ω of bus termination.

> Grove EMG Detector: owned from the thesis work; Seeed list price is ~$30 USD (about €29). No
> oscilloscope is needed, the logic analyzer covers the digital buses and the analog EMG is read via the
> ADC and plotted from serial.

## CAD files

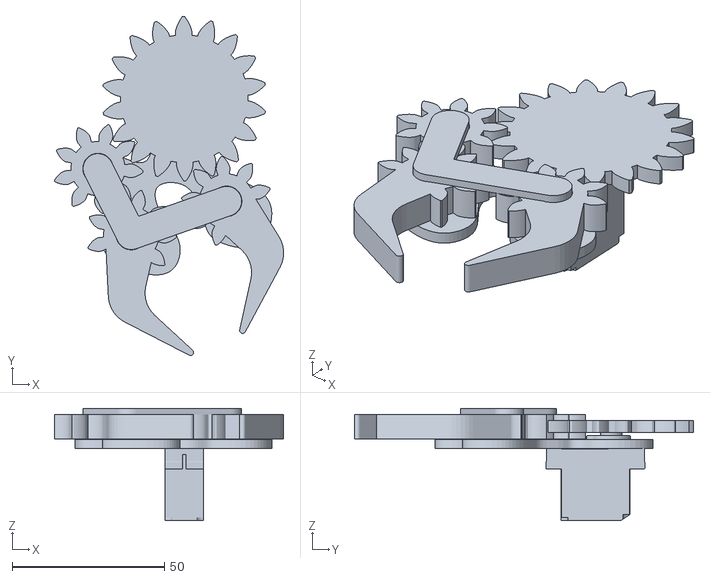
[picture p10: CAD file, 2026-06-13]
cad/gripper_assembly.stl
75.3 x 111.3 x 36.9

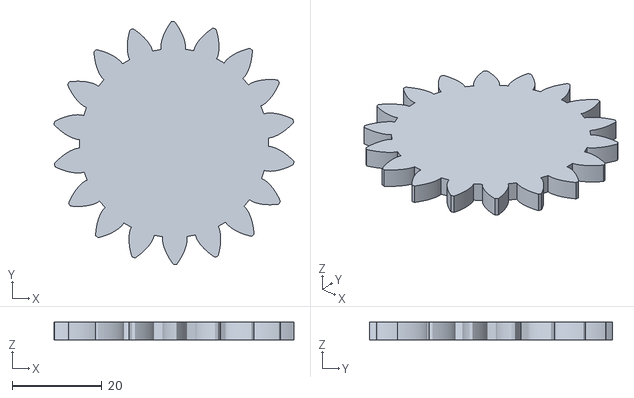
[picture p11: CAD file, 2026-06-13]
cad/print_parts/main_gear.stl
53.4 x 54.0 x 4.00

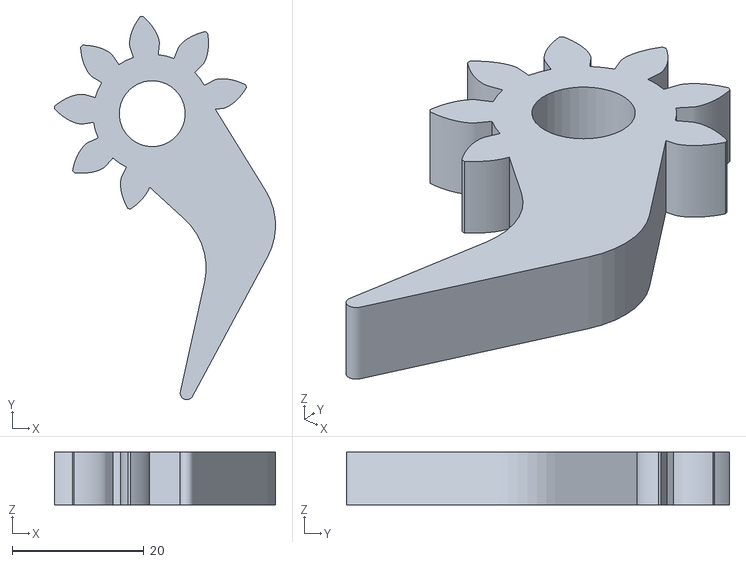
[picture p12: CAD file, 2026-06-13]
cad/print_parts/finger_reverse.stl
33.5 x 58.2 x 8.00

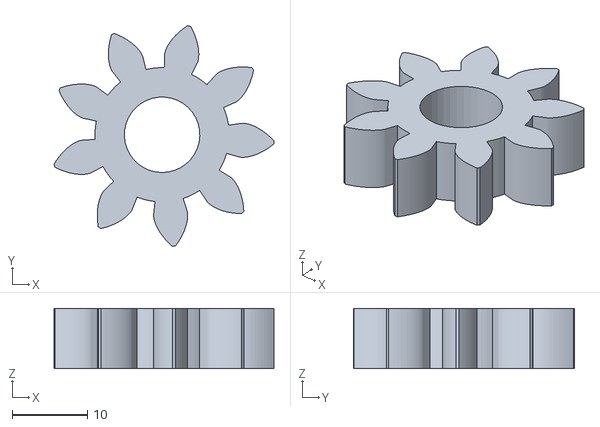
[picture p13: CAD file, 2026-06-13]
cad/print_parts/reverser_gear.stl
29.2 x 29.2 x 8.00

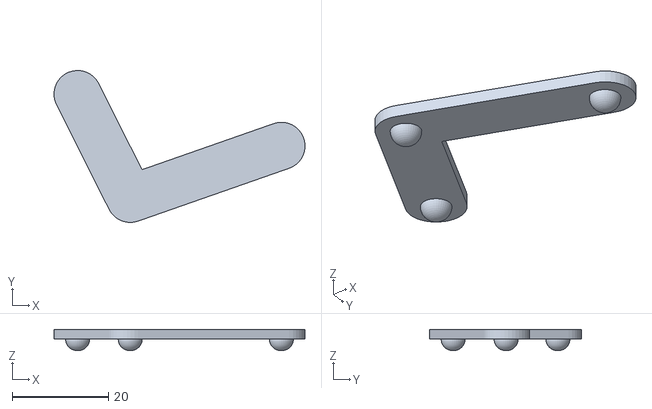
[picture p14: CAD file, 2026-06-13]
cad/print_parts/gripper_top_frame.stl
52.1 x 31.5 x 4.40

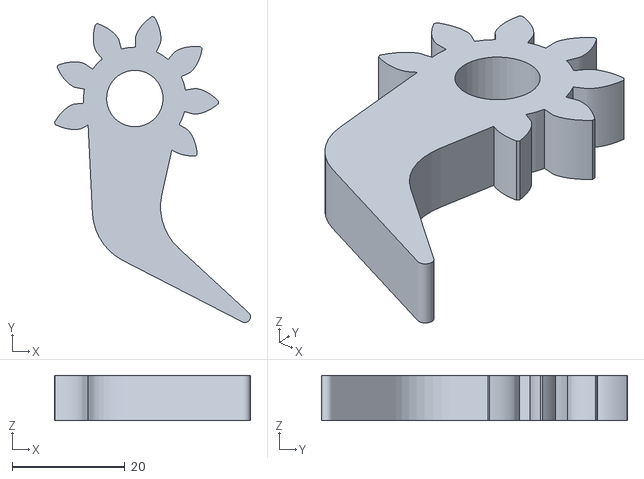
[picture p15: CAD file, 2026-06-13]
cad/print_parts/finger_normal.stl
34.7 x 54.2 x 8.00

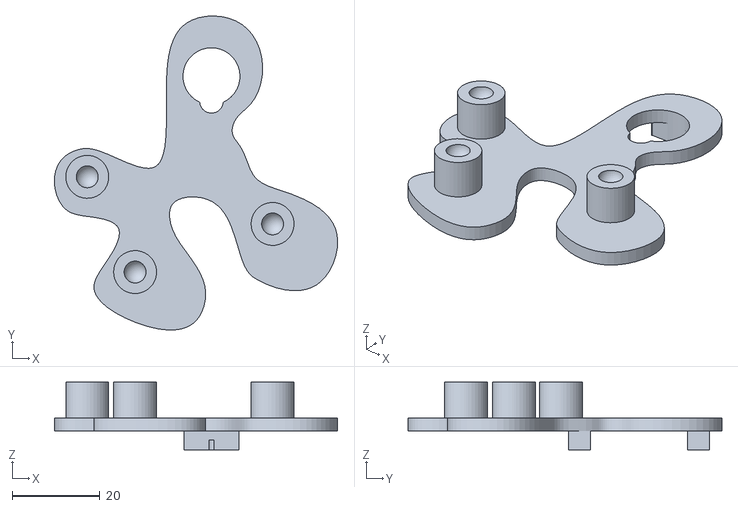
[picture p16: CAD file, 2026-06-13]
cad/print_parts/gripper_bottom_frame.stl
64.6 x 71.6 x 15.5

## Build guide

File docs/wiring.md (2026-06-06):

# Wiring plan : Nucleo-F446RE (DRAFT)

Status: DRAFT. Pins below are a sensible default to start from, NOT yet verified on
the board. Confirm against the Nucleo-F446RE pinout (UM1724) and CubeMX when you wire
it up in Phase 0+. The point of writing it now is to think the I/O through before the
parts land, not to lock it.

Board pinout reference: `STM32_NUCLEO_F446RE_Pinout.png` (in this folder). Note the
two header styles: Arduino headers (CN5/6/8/9, nicknames like A0/D13) and Morpho
headers (CN7/CN10, real chip names like PA0). A0 and PA0 are the SAME physical pin,
two labels. The firmware always uses the chip name (PA0 = GPIOA pin 0).

## Pin map (proposed)

| Function | Signal | STM32 pin | Nucleo header | Notes |
|---|---|---|---|---|
| EMG sensor 1 | ADC1_IN0 | PA0 | A0 | Grove EMG analog envelope in |
| EMG sensor 2 | ADC1_IN1 | PA1 | A1 | second channel (optional) |
| Servo PWM | TIM4_CH1 | PB6 | D10 | SG90 signal (3.3 V PWM is fine) |
| Debug UART TX | USART2_TX | PA2 | (ST-LINK VCP) | prints to PC over the Nucleo USB |
| Debug UART RX | USART2_RX | PA3 | (ST-LINK VCP) | |
| Onboard LED | GPIO | PA5 | D13 / LD2 | blink target for Phase 0 |
| MCP2515 SCK | SPI2_SCK | PB13 | CN10 | SPI2 chosen to avoid the PA5/LD2 clash |
| MCP2515 MISO | SPI2_MISO | PB14 | CN10 | |
| MCP2515 MOSI | SPI2_MOSI | PB15 | CN10 | |
| MCP2515 CS | GPIO out | PB12 | CN10 | software chip-select |
| MCP2515 INT | GPIO in (EXTI) | PA9 | D8 | RX interrupt from controller |
| (opt) native CAN RX | CAN1_RX | PB8 | D15 | only if adding SN65HVD230 |
| (opt) native CAN TX | CAN1_TX | PB9 | D14 | only if adding SN65HVD230 |

Why SPI2 and not SPI1: SPI1's SCK is PA5, which is also LD2 (the onboard LED). It works,
but the LED flickers with every SPI clock. SPI2 (PB13/14/15) keeps them separate.

## Power

- Nucleo: powered + flashed over Mini-USB from the PC (ST-LINK). Mini-USB, not micro,
  not USB-C.
- MCP2515 module: 5 V from the Nucleo 5V pin + GND (low current, fine on USB power).
  Logic is 3.3 V tolerant on most modules; verify your module before trusting MOSI/CS.
- SG90 servo: SEPARATE supply, do NOT run it off the Nucleo 5V pin (current spikes
  brown out the board). 4xAAA (6 V) pack straight to the servo is simplest. CRITICAL:
  tie the servo supply ground to Nucleo GND (battery minus to a GND pin) so the PWM
  signal has a common reference. Without the shared ground the servo will twitch or
  ignore the signal.

## CAN bus

MCP2515-over-SPI is the primary CAN path (the F446 talks SPI to the MCP2515, which is
controller + transceiver). To show traffic with one node: decode the CAN frames on the
24 MHz logic analyzer in PulseView (CAN decoder). For a real two-node exchange: add a
second MCP2515 on an Arduino, or a $3 SN65HVD230 on the F446's native bxCAN (PB8/PB9).

Note: F446 native CAN is bxCAN (classic CAN 2.0), NOT FDCAN. FDCAN is G4/H7 only.

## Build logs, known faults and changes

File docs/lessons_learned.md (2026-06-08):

# EMG Gripper Control , Lessons Learned (2026-06-08)

A full session was spent getting one muscle to drive a gripper. Most of it was spent fighting a
symptom of one root cause. This is the record so future work doesn't repeat it.

## Goal
Single-EMG control of the 3D-printed gripper: at least open/close from one muscle, ideally a
small gesture vocabulary.

## What finally worked (the stable checkpoint)
**Raw-signal threshold TOGGLE.** The centered (pre-rectify) signal dipping below a threshold
(~ -400) toggles the gripper open<->close, one toggle per dip. It **bypasses the envelope
entirely.** CONFIRMED: 12/12 clean perfectly-alternating toggles, as fast as you can contract,
zero double-fires (`logs/dtw_log_260608-182159.csv`).

## THE ROOT CAUSE that wasted most of the session
One muscle contraction produces a **biphasic** raw signal (an up-swing then a down-swing). The
envelope used **full-wave rectification** (`abs()`), which folds the down-swing back up into a
**second positive hump , an "echo."** So every single contraction looked like **two humps** in the
envelope. Every counting/classification scheme was fed this doubled signal and miscounted.
**It was invisible until we plotted the RAW (pre-rectify) signal.** Half-wave rectify
(`max(x,0)`) removes the echo; the toggle avoids the envelope altogether.

## Approaches tried, in order, and why each failed
1. **Amplitude-coded DTW** (weak pulse = open, strong = close; classify by contraction INTENSITY).
   FAILED: amplitude is the least reproducible EMG feature , the *same* intended contraction came
   out env 98 one try and 617 another (`...141530` vs `...141651`). Fatigue / electrode drift /
   effort all move it. And at low activity the smaller template is always the closest match, so
   weak activity defaulted to "open."
2. **Timing-debounce FSM** (single vs double pulse, pulses separated by a TIMED gap). FAILED:
   needed the dip between two pulses to LAST >= ~0.12 s; real fast doubles dipped deep but BRIEF
   (~45 ms), so they merged into one (false close). Tightening the gap risked splitting jerky
   singles.
3. **Blip-counting on the envelope** (pulses separated by AMPLITUDE , env dipping below a re-arm
   line, not by a timed gap). Better idea. FAILED on the ECHO: each contraction's echo hump made
   phantom extra "blips," and the echo's zero-crossing made phantom "releases." Singles became
   doubles, doubles became singles.
4. **Band-aids stacked on #3 (all treating echo symptoms, all later removed):**
   - reprime/flush on decision -> a dc-poisoning bug (reseeding the slow DC tracker mid-contraction
     made env read garbage ~5-15 s). Patched by clearing rings only.
   - min-peak gate (a pulse must peak above X) -> rejected weak echoes but also weak real taps.
   - re-arm dwell (stay low ~0.1 s to re-arm) -> rejected brief echo dips but ALSO fast real
     doubles (their release was 1 sample, same as an echo dip). A forced, false trade-off.
   - 20 Hz high-pass -> REVERTED: the Grove sensor output is an already-enveloped LOW-frequency
     signal, so a 20 Hz HP destroyed it (movements -> tiny jitter; env -> slow sine).
   - startup fast-DC-settle + median-seed prime -> genuine small fixes (kept), not the core issue.
5. **The misdiagnosis: "electrode dropouts."** For ~6 iterations the env crashing mid-contraction
   (375->55->269) was blamed on the dying electrode and "fresh pads" was the recommended fix.
   WRONG , the raw signal was clean. The crash was env passing through the biphasic swing's
   zero-crossing; the "recovery" was the rectified echo. Found ONLY after adding a raw-signal view.

## Process lessons (Can's, in his words)
- **Get a working checkpoint at the simplest level FIRST, then build up.** Can knew the simple
  approach would work but skipped it to chase a fancier version , building toward a destination on
  a foundation that wasn't meant to support it.
- **A label can anchor you.** Once DTW was tagged "fragile," that label blocked an objective look
  and a return to basics; effort went into the half-built foundation instead of a reset.
- **When a DERIVED signal (envelope, DTW distance) looks broken, look at the RAW signal FIRST.**
  Don't theorize about hardware from a processed signal. operate.py's top "RAW signal" panel
  exists for exactly this , add it / check it before blaming the electrode.
- **One change at a time, verified.** When band-aids start stacking, you're treating symptoms ,
  stop and find the root cause.

## Current code state (post-reset)
- `emg_studio.py`: notch -> DC-tracker (fast-settle first ~1.5 s) -> **half-wave** rectify -> MA
  envelope. (Half-wave kept; the echo is gone, though the decision no longer uses the envelope.)
- `operate.py`: raw-signal **toggle** decision (`sb_thr`). 3 plots (raw / env / DTW) + CSV log.
  DTW is computed for the plot only , it drives nothing.
- Build-up path: "1 dip = close, 2 dips = open" on top of the proven raw-dip detector.

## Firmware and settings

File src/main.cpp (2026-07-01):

// main.cpp : the standalone myoelectric gripper under FreeRTOS. servoTask (~200 Hz) + commsTask (~50 Hz
// serial telemetry) + canTask (CAN: gesture event + ~5 Hz status heartbeat) + watchdogTask. The 1 kHz
// brain runs in the DMA callback and hands each flex to servoTask AND canTask via queues.
#include "stm32f4xx_hal.h"
#include "FreeRTOS.h"
#include "task.h"
#include "queue.h"
#include "Emg.h"
#include "Servo.h"
#include "Comms.h"
#include "MuscleTrigger.h"
#include "Watchdog.h"
#include "Mcp2515CanBus.h"

extern "C" void xPortSysTickHandler(void);   // the kernel tick, defined in the ARM_CM4F port

// the parts (built cheaply here; real setup happens in init())
static Emg           emg;
static Servo         servo;
static Comms         comms;
static MuscleTrigger trigger;
static Watchdog      watchdog;
static Mcp2515CanBus canBus;

// The brain (DMA ISR) drops one token in here per valid flex; servoTask waits on it. This replaces the
// old volatile flag: a queue is the safe ISR->task hand-off, it does the locking, so no manual volatile.
static QueueHandle_t mailBox;
// A second copy of the same flex signal, for canTask to announce the gesture over CAN immediately.
static QueueHandle_t canMailBox;

// servoTask : highest priority. Waits on the flex queue, toggles on a flex, eases every cycle.
static void servoTask(void *params)
{
    (void)params;
    uint8_t token;
    while (1)
    {
        // block up to 5 ms for a flex; the timeout doubles as the ~200 Hz pacing (replaces vTaskDelay)
        if (xQueueReceive(mailBox, &token, pdMS_TO_TICKS(5)) == pdTRUE)
        {
            servo.toggle();   // a flex arrived
        }
        servo.ease();         // glide toward the target every cycle
    }
}

// commsTask : telemetry to the laptop viewer. ~50 Hz is plenty (the viewer refreshes ~30/sec).
static void commsTask(void *params)
{
    (void)params;
    while (1)
    {
        uint16_t raw      = emg.read();
        int      centered = trigger.centered();
        comms.sendStatus(raw, centered, trigger.isElectrodeAttached());
        vTaskDelay(pdMS_TO_TICKS(20));   // ~50 Hz
    }
}

// canTask : reports the gripper over CAN. Blocks on canMailBox with a 200 ms timeout (the servoTask
// pattern): a queued token (the brain just saw a flex) -> send an immediate GESTURE frame (ID 0x100);
// a timeout -> send a periodic status heartbeat (ID 0x101). Both carry the same two bytes,
// [gripper closed? 0/1][electrode attached? 0/1]. SPI2 is canTask's alone, so no locking is needed.
static void canTask(void *params)
{
    (void)params;
    uint8_t token;
    while (1)
    {
        // Sleep here until either a flex token arrives OR 200 ms passes (then it's a heartbeat).
        bool gesture = (xQueueReceive(canMailBox, &token, pdMS_TO_TICKS(200)) == pdTRUE);

        uint8_t status[2] = { (uint8_t)servo.isClosed(),                 // bool -> 1 (closed) / 0 (open)
                              (uint8_t)trigger.isElectrodeAttached() };  // bool -> 1 (attached) / 0 (detached)

        uint16_t frameId;
        if (gesture)
            frameId = 0x100;   // a flex just happened -> immediate gesture event
        else
            frameId = 0x101;   // nothing new -> periodic status heartbeat
        canBus.sendFrame(frameId, status, 2);   // both frames carry the same 2 status bytes; only the ID differs
    }
}

// watchdogTask : lowest priority. Pets the IWDG every 500 ms (well inside the ~2 s timeout). Being lowest
// IS the safety: if a higher task hangs and never yields, this never runs -> never pets -> the chip reboots.
static void watchdogTask(void *params)
{
    (void)params;
    while (1)
    {
        watchdog.pet();
        vTaskDelay(pdMS_TO_TICKS(500));
    }
}

int main(void)
{
    HAL_Init();          // HAL + its 1 ms SysTick
    emg.init();
    servo.init();
    comms.init();
    watchdog.init();     // arm the IWDG; watchdogTask feeds it

    // CAN: bring up the MCP2515 over SPI2 and go live on the bus (Normal mode). canTask broadcasts status.
    canBus.init();
    canBus.reset();
    canBus.setBitTiming8MHz500k();   // 8 MHz crystal @ 500 kbps; must match the other node(s)
    canBus.enterNormalMode();

    canMailBox = xQueueCreate(4, sizeof(uint8_t));   // brain -> canTask : announce each flex over CAN
    mailBox    = xQueueCreate(4, sizeof(uint8_t));   // brain -> servoTask : act on each flex
    configASSERT(mailBox != NULL && canMailBox != NULL);   // out of heap -> stop here so it's obvious
    // (canMailBox is created first, so when the ISR sees mailBox != NULL, canMailBox is ready too.)

    // priorities (higher = more urgent; idle is 0): servo preempts comms/can preempts watchdog.
    xTaskCreate(servoTask,    "servo",    256, nullptr, 3, nullptr);   // highest: actuation must not be delayed
    xTaskCreate(commsTask,    "comms",    512, nullptr, 2, nullptr);   // serial telemetry
    xTaskCreate(canTask,      "can",      256, nullptr, 2, nullptr);   // CAN status heartbeat
    xTaskCreate(watchdogTask, "watchdog", 128, nullptr, 1, nullptr);   // lowest: starved if anything above hangs
    vTaskStartScheduler();                                             // hand the CPU to the kernel; does NOT return

    while (1) { }        // only reached if the scheduler could not start
}

// Interrupt handlers. SysTick feeds BOTH HAL and the kernel. The 1 kHz brain runs in the ADC/DMA callback.
extern "C" void SysTick_Handler(void)
{
    HAL_IncTick();
    if (xTaskGetSchedulerState() != taskSCHEDULER_NOT_STARTED) { xPortSysTickHandler(); }
}

// The 1 kHz brain. On a valid flex, hand a token to servoTask via the queue, then yield so the higher-
// priority servoTask runs the instant this ISR exits. The DMA interrupt is priority 5 (the syscall
// ceiling), so calling xQueueSendFromISR from here is allowed.
extern "C" void HAL_ADC_ConvCpltCallback(ADC_HandleTypeDef *h)
{
    if (mailBox != NULL && trigger.update(emg.read()))   // queues are NULL until the scheduler is set up
    {
        uint8_t token = 1;
        BaseType_t higherPriorityTaskWoken = pdFALSE;
        xQueueSendFromISR(mailBox,    &token, &higherPriorityTaskWoken);   // wake servoTask (toggle)
        xQueueSendFromISR(canMailBox, &token, &higherPriorityTaskWoken);   // wake canTask (announce over CAN)
        portYIELD_FROM_ISR(higherPriorityTaskWoken);
    }
}
extern "C" void DMA2_Stream0_IRQHandler(void) { emg.handleDmaIrq(); }

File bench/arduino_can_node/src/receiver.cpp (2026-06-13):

// receiver.cpp : Arduino UNO + MCP2515 (8 MHz). Prints every CAN frame received. (PlatformIO env: receiver)
// Open the serial monitor at 115200 to watch frames arrive.
#include <Arduino.h>
#include <SPI.h>
#include <mcp_can.h>

const int SPI_CS_PIN = 10;          // MCP2515 CS -> Arduino D10
MCP_CAN CAN(SPI_CS_PIN);

void setup() {
  Serial.begin(115200);
  while (CAN.begin(MCP_ANY, CAN_500KBPS, MCP_8MHZ) != CAN_OK) {   // same 500 kbps + 8 MHz as the sender
    Serial.println(F("MCP2515 init FAILED (check wiring/crystal), retrying..."));
    delay(500);
  }
  CAN.setMode(MCP_NORMAL);
  Serial.println(F("Receiver ready, waiting for frames..."));
}

void loop() {
  if (CAN.checkReceive() == CAN_MSGAVAIL) {     // a frame is waiting (polled; no INT wire needed)
    unsigned long id = 0;
    byte len = 0;
    byte data[8];
    CAN.readMsgBuf(&id, &len, data);

    // Gripper frames (2 bytes): 0x100 = gesture event, 0x101 = status heartbeat. Decode for the demo.
    if ((id == 0x100 || id == 0x101) && len == 2) {
      Serial.print(id == 0x100 ? F("GESTURE  servo=") : F("Status   servo="));
      Serial.print(data[0] ? F("CLOSED") : F("OPEN"));
      Serial.print(F("   electrode="));
      Serial.println(data[1] ? F("ATTACHED") : F("DETACHED"));
      return;
    }

    // Anything else: raw byte dump (the generic bench view).
    Serial.print(F("Got frame  id=0x")); Serial.print(id, HEX);
    Serial.print(F("  len="));           Serial.print(len);
    Serial.print(F("  data="));
    for (byte i = 0; i < len; i++) {
      if (data[i] < 0x10) Serial.print('0');
      Serial.print(data[i], HEX); Serial.print(' ');
    }
    Serial.println();
  }
}

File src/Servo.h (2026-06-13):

// Servo : the gripper (SG90, PWM on PB6 / D10). open()/close()/toggle() pick a position;
// ease() (call every loop) glides toward it, never slamming the printed gears.
#ifndef SERVO_H
#define SERVO_H
#include "stm32f4xx_hal.h"

class Servo
{
  public:
    void init()
    {
        __HAL_RCC_GPIOB_CLK_ENABLE();      // turn on power to port B (PB6 lives here)
        __HAL_RCC_TIM4_CLK_ENABLE();       // turn on power to timer 4 (it makes the PWM)

        // hand PB6 over to timer 4 ("alternate function 2") so the timer can drive the pin
        GPIO_InitTypeDef g = {0};
        g.Pin = GPIO_PIN_6; g.Mode = GPIO_MODE_AF_PP; g.Pull = GPIO_NOPULL;
        g.Speed = GPIO_SPEED_FREQ_LOW; g.Alternate = GPIO_AF2_TIM4;
        HAL_GPIO_Init(GPIOB, &g);

        // tick once per microsecond (16 MHz / 16), roll over every 20 ms = 50 Hz servo frame
        htim.Instance           = TIM4;
        htim.Init.Prescaler     = 16 - 1;
        htim.Init.CounterMode   = TIM_COUNTERMODE_UP;
        htim.Init.Period        = 20000 - 1;
        htim.Init.ClockDivision = TIM_CLOCKDIVISION_DIV1;
        HAL_TIM_PWM_Init(&htim);

        TIM_OC_InitTypeDef oc = {0};
        oc.OCMode = TIM_OCMODE_PWM1; oc.Pulse = OPEN; oc.OCPolarity = TIM_OCPOLARITY_HIGH;
        HAL_TIM_PWM_ConfigChannel(&htim, &oc, TIM_CHANNEL_1);
        HAL_TIM_PWM_Start(&htim, TIM_CHANNEL_1);

        targetPosition = currentPosition = OPEN;
        closed = false;
    }

    void open()   { closed = false; targetPosition = OPEN;  }   // choose the open position
    void close()  { closed = true;  targetPosition = CLOSE; }   // choose the closed position
    void toggle() { if (closed) open(); else close(); }         // flip between them

    bool isClosed() const { return closed; }                    // current state (for CAN/serial telemetry)

    // Call every loop: move at most 'slew' us toward the target, then write it to the PWM.
    void ease()
    {
        int step = targetPosition - currentPosition;   // how far we still have to go
        if (step >  slew) step =  slew;                // ...but never more than 'slew' per call,
        if (step < -slew) step = -slew;                //    in either direction
        currentPosition += step;                       // (step is 0 when we're already there)
        __HAL_TIM_SET_COMPARE(&htim, TIM_CHANNEL_1, currentPosition);
    }

    // Adjust how fast the gripper moves: microseconds of travel per step (bigger = faster).
    void setRotationSpeed(int speed) { slew = clampToRange(speed, 1, 20); }

  private:
    // Pulse widths in us, measured for OUR gripper (within the SG90's safe ~1270-1620 band).
    static const int OPEN = 1300, CLOSE = 1600;

    static int clampToRange(int value, int low, int high)
    {
        if (value < low)  return low;
        if (value > high) return high;
        return value;
    }

    TIM_HandleTypeDef htim = {};
    int  slew = 4;                  // microseconds moved per step = rotation speed
    int  targetPosition  = OPEN;    // where we want to be
    int  currentPosition = OPEN;    // where we are now (eased toward the target)
    bool closed = false;            // current gripper state
};
#endif

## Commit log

2026-06-05 Scaffold STM32-EMG-Biosignal: PlatformIO + stm32cube, CI, docs
2026-06-06 EMG bring-up: timer ADC @1kHz, adaptive bias, 50Hz notch envelope; pinout+docs
2026-06-06 Servo bring-up: SG90 50Hz PWM sweep on TIM4/PB6 (90deg confirmed); update plan
2026-06-07 EMG-driven gripper: operate.py sends servo commands (open 1350/close 1650), firmware safe-clamped + boots open; gear_designer.py (involute generator + DXF + mesh calculator); slot colors; SIGINT-immu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
    [dtw_log_260607-162657.csv, dtw_log_260607-162731.csv, dtw_log_260607-163228.csv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]
2026-06-07 gear_designer: fix inverted tooth flank (teeth now taper to the tip, not widen)
2026-06-08 Add HANDOFF.md (working state, architecture, tools, learnings, open items)
    [dtw_log_260608-125758.csv, dtw_log_260608-130725.csv, dtw_log_260608-131142.csv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]
2026-06-08 EMG gripper: working raw-signal toggle control (stable checkpoint)
    Raw centered signal dipping below -threshold toggles the gripper open<->close,
    one toggle per dip. Bypasses the envelope entirely. Confirmed 12/12 clean
    alternating toggles, fast, zero double-fires (logs/dtw_log_260608-182159.csv).
    Root cause of the long saga: full-wave rectify (abs) folded each biphasic
    contraction's down-swing into a phantom 'echo' hump, so every contraction read as
    two humps and broke all envelope-based counting/classification. Found by plotting
    the raw pre-rectify signal.
    Also in this checkpoint: half-wave rectify, DC fast-settle + median-seed prime,
    calibrate full-capture re-trim, raw-signal plot panel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
    [dtw_log_260607-124633.csv, dtw_log_260607-131127.csv, dtw_log_260607-131240.csv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]
2026-06-09 Firmware: C++ header-only classes (Emg/Servo/Comms/Timer) + slim main.cpp; operate.py back to single-dip toggle; add FIRMWARE_MAP nav doc; drop per-file banner comments
2026-06-09 chip_monitor: fix lag (fixed X range + decimated logging like operate.py, reader off the disk path); single centered plot; antialias flag (default off) for smooth fullscreen
    [chip_monitor.py]
2026-06-09 Audit corrections: FreeRTOS is an OPEN deliverable, not a settled cut and not Can's decision; flag DMA+timer-ADC and CMSIS-DSP as known scope deviations (not done); fix 'day one' -> start of 5th sess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
2026-06-09 IWDG watchdog: auto-reboot a hung loop, verified by a deliberate hang test
    - Watchdog.h: hardware IWDG wrapper (init arms ~2 s, pet() refreshes). This HAL is the
    2016 driver: Init is {Prescaler, Reload} (no Window) and HAL_IWDG_Init is also the start.
    - main.cpp: arm just before the loop; pet() as the last line each iteration, so a hang
    anywhere stops the petting and the chip reboots within ~2 s.
    - Verified on hardware: a forced infinite loop froze the board and it auto-rebooted ~2 s
    later, repeatedly.
    - Docs: FIRMWARE_MAP / HANDOFF / phased_plan mark IWDG done; also folds in the earlier
    audit-residual reconciliation (phased_plan stale "DONE" claims, HANDOFF "does the DSP").
    [main.cpp]
2026-06-09 On-chip 50 Hz notch filter: kill mains hum (DSP box)
    Notch.h: a 50 Hz biquad notch applied to the centered signal in MuscleTrigger. Re-derived for the 200 Hz loop (50 Hz is fs/4, so it collapses to a clean 3-term biquad). Verified on hardware: the mains-hum band collapsed to a clean line and the flex dip is unchanged. Docs: FIRMWARE_MAP, phased_plan, HANDOFF mark the notch done; CMSIS-DSP library swap and feature extraction stay optional.
    [MuscleTrigger.h]
2026-06-11 FreeRTOS B2: EMG runs as servoTask + commsTask + watchdogTask
    Restored the EMG firmware on the FreeRTOS scaffold and split the old 200 Hz superloop into three tasks: servoTask (~200 Hz, flex toggle + ease), commsTask (~50 Hz, telemetry), watchdogTask (500 ms, pets the IWDG). The 1 kHz brain stays in the ADC/DMA callback.
    Only shared state is the volatile toggleRequested flag (brain -> servoTask); raw/centered are local to commsTask. All tasks priority 1 for now; Step C sets priorities (servo high, comms mid, watchdog lowest).
    Added tools/emg_studio/requirements.txt (numpy/pyserial/PyQt6/pyqtgraph) so the viewer env is reproducible.
    Verified on hardware: smooth toggle, telemetry streams (n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
    [main.cpp]
2026-06-11 FreeRTOS Step C + queue: task priorities + brain->servo handoff via a queue
    Step C: priorities servo(3) > comms(2) > watchdog(1). The watchdog task is LOWEST on purpose, if a higher task hangs and never yields, it starves the pet and the IWDG reboots the chip (a real, demoable safety property).
    Queue: replaced the volatile toggleRequested flag with a FreeRTOS queue (mailBox). The 1 kHz brain does xQueueSendFromISR + portYIELD_FROM_ISR on a valid flex; servoTask blocks on xQueueReceive whose 5 ms timeout doubles as the ~200 Hz pacing. The DMA ISR sits at priority 5 (the syscall ceiling), so FromISR is allowed. No shared volatile anymore.
    Viewer: chip_monitor.py now defaults --fs 50 (matches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
    [chip_monitor.py, main.cpp]
2026-06-12 Handoff for chat 8: docs to FreeRTOS+queue state; CAN hardware validated on the Arduino bench
    Rewrote HANDOFF.md / FIRMWARE_MAP.md / NEXT_CHAT_PROMPT.md from the old super-loop description to the current state: 3 FreeRTOS tasks (servo/comms/watchdog) + the mailBox queue + the watchdog-starvation reboot, plus the load-bearing hard-float build wiring note (platformio.ini + fpu_link.py) and the validated CAN-hardware status.
    Added the CAN bench-validation artifacts: docs/Logic_Analyzer_CAN_Comms.png (SPI-decoded frame on the logic analyzer) and the PulseView session (.sr capture + .pvs view).
    Handoff 7 was also appended to STM32_project_goals.md (separate CareerAssistant location, not in this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
2026-06-12 CAN step 1: MCP2515 SPI2 bring-up; read CANSTAT=0x80, verified on hardware
    Add Mcp2515CanBus.h: SPI2 master (mode 0, 2 MHz, software CS on PB12), reset() and readRegister() over the MCP2515's 3-byte READ protocol. A temporary probe loop in main() resets the chip and prints CANSTAT once a second; reads 0x80 (Configuration mode) on hardware, proving SPI + wiring (5V module, 3.3V signals fine) + CS framing. Probe pauses the normal FreeRTOS firmware (watchdog not armed) so CAN is tested in isolation; it gets deleted once CAN is built. Also: Comms.sendLine() for bring-up messages, and a mailBox!=NULL guard in the brain ISR so a flex during the probe (queue not created yet) can't send to a null qu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
    [main.cpp]
2026-06-12 CAN step 2: writeRegister + bit timing (8MHz/500k) + Normal mode, verified
    Add Mcp2515CanBus::writeRegister() (the MCP2515 WRITE: [0x02][addr][value], one CS frame, transmit-only). Add setBitTiming8MHz500k() (CNF1/2/3 = 0x00/0x90/0x82, the bench-proven values so the STM32 a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
2026-06-13 Extract MCP2515 register map into Mcp2515Registers.h (no behavior change)
    Move every command byte, register address, and bit-field value out of the driver into a dedicated Mcp2515Registers.h with datasheet acronyms in the comments, so Mcp2515CanBus.h reads as pure logic an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
2026-06-13 CAN step 3b: real two-node transmit, STM32 -> Arduino over CAN, verified
    Switch the probe from loopback to Normal mode and send-only (no readback: in normal mode our frame goes out to the other node, not back to us). STM32 broadcasts id=0x100 'EMG'+counter once a second; 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
2026-06-13 Integrate CAN into the live firmware: canTask broadcasts a status heartbeat
    Remove the bench probe and restore the full FreeRTOS gripper, now with a 4th task. canTask (pri 2) broadcasts a 2-byte status frame [closed?, signal-valid?] under ID 0x101 every 200 ms, so the running device reports its state over CAN while the 1 kHz brain, servo, serial telemetry, and IWDG all keep running. Watchdog stays uniquely lowest so the starvation-reboot safety holds. Add Servo::isClosed() for telemetry. Verified on hardware: Arduino receives id=0x101 heartbeats at ~5 Hz.
    [Servo.h, main.cpp]
2026-06-13 Rename MuscleTrigger::isValid() -> isElectrodeAttached() for clarity
    Matches the existing internal flag name (electrodesConnected) and reads clearly at the call sites (commsTask, canTask). Behavior-identical (same firmware size).
2026-06-13 CAN: add instant gesture-event frame (0x100) alongside the status heartbeat (0x101)
    Brain ISR now drops a token to a second queue (canMailBox) on each flex. canTask blocks on it with a 200 ms timeout: a token -> immediate GESTURE frame (ID 0x100); a timeout -> periodic status heartbeat (ID 0x101). Both carry the same 2 status bytes [closed?, electrode-attached?]; only the ID differs. canMailBox is created before mailBox so the existing 'mailBox != NULL' ISR guard covers both. Readability: chose if/else over a ternary for the frame ID, and bool->uint8_t casts instead of '? 1 : 0'. Verified on hardware: GESTURE on each flex, Status between, failsafe shows electrode=DETACHED with no toggling.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
    [main.cpp]
2026-06-13 Remove dead serial-receive path; Comms is now one-way TX telemetry
    The S<us> serial-command path was a leftover from the early laptop-driven-servo era; the gripper is autonomous now (EMG drives it) and nothing sends to the board, so the entire receive path was dead.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
2026-06-13 Add the Arduino CAN bench node (receiver/sender) for reproducible two-node CAN
    Moved from a separate workspace into bench/arduino_can_node/ so the repo is self-contained and the CAN claim is verifiable. README notes the deliberate contrast: this node uses the off-the-shelf cory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
2026-06-13 Cleanup: remove vestigial Timer.h; ignore vendor datasheet copies
    Timer.h was unused since the FreeRTOS port (vTaskDelay + the queue timeout replaced it). Also gitignore the Microchip datasheet copies in docs/ (freely available; values live in src/Mcp2515Registers.h).
2026-06-13 Mechanical: add gripper CAD render, open/close animation, and STL files
    SolidWorks render (docs/gripper_cad.png), motion GIF (docs/gripper_animation.gif), assembly STL for GitHub's 3D viewer (cad/gripper_assembly.stl), and the 6 printable parts (cad/print_parts/). Shows 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
    [finger_normal.stl, finger_reverse.stl, gripper_assembly.stl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]
2026-06-13 Add demo video, logic-analyzer captures, and BOM
    Compressed 30s demo (docs/demo_video_STM32.mp4, 6.6 MB), hero still, PulseView SPI captures + raw .sr/.pvs, the termination-fix log, and docs/BOM.md.
2026-06-13 Ship docs: recruiter-first README + refresh nav/handoff docs
    Rewrite README firmware-led (what-it-demonstrates, Mermaid architecture, the CAN story + capture, Mechanical section, BOM, thesis links, contact); refresh FIRMWARE_MAP (4 tasks + 2 queues + CAN), HAN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
2026-06-13 Polish for public: README, platformio comments, CAD image crop
    Mermaid diagram simplified + connected; CAD render cropped to match the animation height; contact one-per-line; removed remaining 'not Arduino' phrasing; interpunct separators replaced with pipes; platformio.ini comments trimmed; phased_plan path ref removed; FIRMWARE_MAP HANDOFF ref repointed to README.
2026-06-14 README + docs: AI-tells scrub (no history rewrite needed)
    Per S:\Coding\CodingPlaybooks\PUBLIC_REPO_AI_CLEANUP_FLAGS.md.
    Classification pass found the repo authorship-clean (the 1 'claude'
    hit in history is a commit body mentioning the .claude/ folder being
    untracked, plus a .gitignore line for the same path; no
    Case B prose scrub:
    - README.md: dropped the U+25B6 play-arrow prefix on the demo link;
    replaced U+2192 right-arrows with ASCII '->' or commas; dropped the
    &rarr; HTML entity on the 3D viewer link; dropped the '> Note on the
    build:' block-quote callout in favour of a plain paragraph.
    - docs/gripper_mechanics.md: title space-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
2026-07-01 Add .gitattributes to pin line endings to LF
2026-07-01 Fix stale FIRMWARE_MAP reference in main.cpp; drop .gitignore comments
    [main.cpp]
2026-07-02 Rename project to CAN-Networked Real-Time Myoelectric Gripper Firmware
